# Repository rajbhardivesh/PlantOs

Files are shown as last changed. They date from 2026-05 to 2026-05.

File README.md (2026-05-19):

# 🌱 PlantOS – Smart IoT Plant Monitoring & Automation System






---

## 🚀 Overview

**PlantOS** is a complete **IoT-based plant monitoring and automation system** designed for real-world deployment.

It integrates:
- 📡 Embedded Firmware (ESP32)
- ⚡ Custom PCB Hardware
- 🌐 Web Dashboard
- ☁️ MQTT Cloud Communication

The system continuously monitors environmental conditions and automatically controls irrigation and lighting.

---

## 📸 Hardware Preview

Custom ESP32-based PCB for plant monitoring and automation.

---

## ✨ Key Features

### 🌡️ Multi-Sensor Monitoring
- DHT22 → Temperature & Humidity  
- DS18B20 → High-accuracy temperature  
- PT100 → Industrial temperature sensing  
- BH1750 → Light intensity (Lux)  
- MQ135 → Air quality monitoring  
- Soil Moisture Sensor  

---

### ⚡ Smart Automation
- 💧 Automatic irrigation based on soil moisture  
- 💡 Automatic lighting based on ambient lux  
- ⚙️ Relay-based control system  

---

### 🌐 IoT Connectivity
- WiFi provisioning via Serial interface  
- Secure MQTT communication (TLS supported)  
- Real-time JSON data streaming  

---

### 🧠 Intelligent Calibration System

Supports runtime calibration via commands:

```
cal dht_temp
cal soil
cal pt100
cal mq135
```

✔ Stored in non-volatile memory (NVS)  
✔ No need to reconfigure after reboot  

---

### 💡 LED Status Indicator

| State | Meaning |
|---|---|
| 🔴 Solid | No WiFi |
| 🔴 Blinking | WiFi connected, MQTT disconnected |
| 🔵 Blinking | Fully connected |

---

## 🧱 Hardware Specifications

### 🔌 Microcontroller
- ESP32

### 🔁 Outputs
| Device | GPIO |
|---|---|
| Pump Relay | GPIO21 |
| Light Relay | GPIO19 |

### 📥 Inputs
| Sensor | GPIO |
|---|---|
| DHT22 | GPIO4 |
| BH1750 | GPIO25, GPIO26 |
| MQ135 | GPIO14 |
| DS18B20 | GPIO32 |
| Soil Sensor | GPIO33 |
| PT100 | GPIO36 |

---

## 📡 MQTT Configuration

### Default Settings

```json
{
  "server": "f388acb36bf542b69c0c3cb96cb2cb16.s1.eu.hivemq.cloud",
  "port": 8883,
  "user": "plantos",
  "topic": "device/RDH001/data"
}
```

---

## 📊 Data Format (Published JSON)

```json
{
  "ssid": "YourWiFi",
  "dht_temp": 28.5,
  "dht_hum": 60.2,
  "soil_pct": 45.0,
  "lux": 320.5,
  "mq135": 210,
  "ds18b20": 27.1,
  "pt100": 26.9,
  "relay1": true,
  "relay2": false
}
```

---

## 🧩 Repository Structure

```
root/
│
├── index.html          # 🌐 Web Dashboard
├── web/src             # Frontend (JS, CSS)
├── pcb/source          # PCB Design Files
├── firmware            # ESP32 Firmware
```

---

## ⚙️ Setup Guide

### 1. Flash Firmware
- Open in Arduino IDE / PlatformIO  
- Select ESP32 board  
- Upload firmware  

### 2. Configure WiFi

Open Serial Monitor (115200 baud):

```
connect
```

### 3. Configure MQTT (Optional)

```
connect mqtt
```

### 4. Launch Dashboard

Open:
```
index.html
```

---

## 📟 Serial Commands

| Command | Description |
|---|---|
| connect | Scan WiFi |
| connect mqtt | Configure MQTT |
| status | System status |
| help | Show commands |
| cal <sensor> | Calibrate |

---

## 🔄 Automation Logic

### Pump
- ON → Soil < 25%
- OFF → Soil > 80%

### Light
- ON → Lux < 200
- OFF → Lux > 10000

---

## 🧠 Firmware Highlights

- Non-blocking state machine
- Auto reconnect WiFi
- MQTT keep-alive
- Persistent storage (NVS)
- JSON telemetry system

---

## 🌍 Use Cases

- Smart Agriculture
- Greenhouses
- Indoor Plants
- Research Labs
- Industrial IoT

---

## 📈 Future Roadmap

- Mobile App
- OTA Updates
- Cloud Dashboard
- LoRa Mode
- AI Automation

---

## Speacial  Thanks To 
PCB Design :  Rajbhar Divesh
Firmware & Web Dashboard: Varikar Manan 
 : 
## Author
** Varikar Manan **
## back-end Author 
** himanshu dave **

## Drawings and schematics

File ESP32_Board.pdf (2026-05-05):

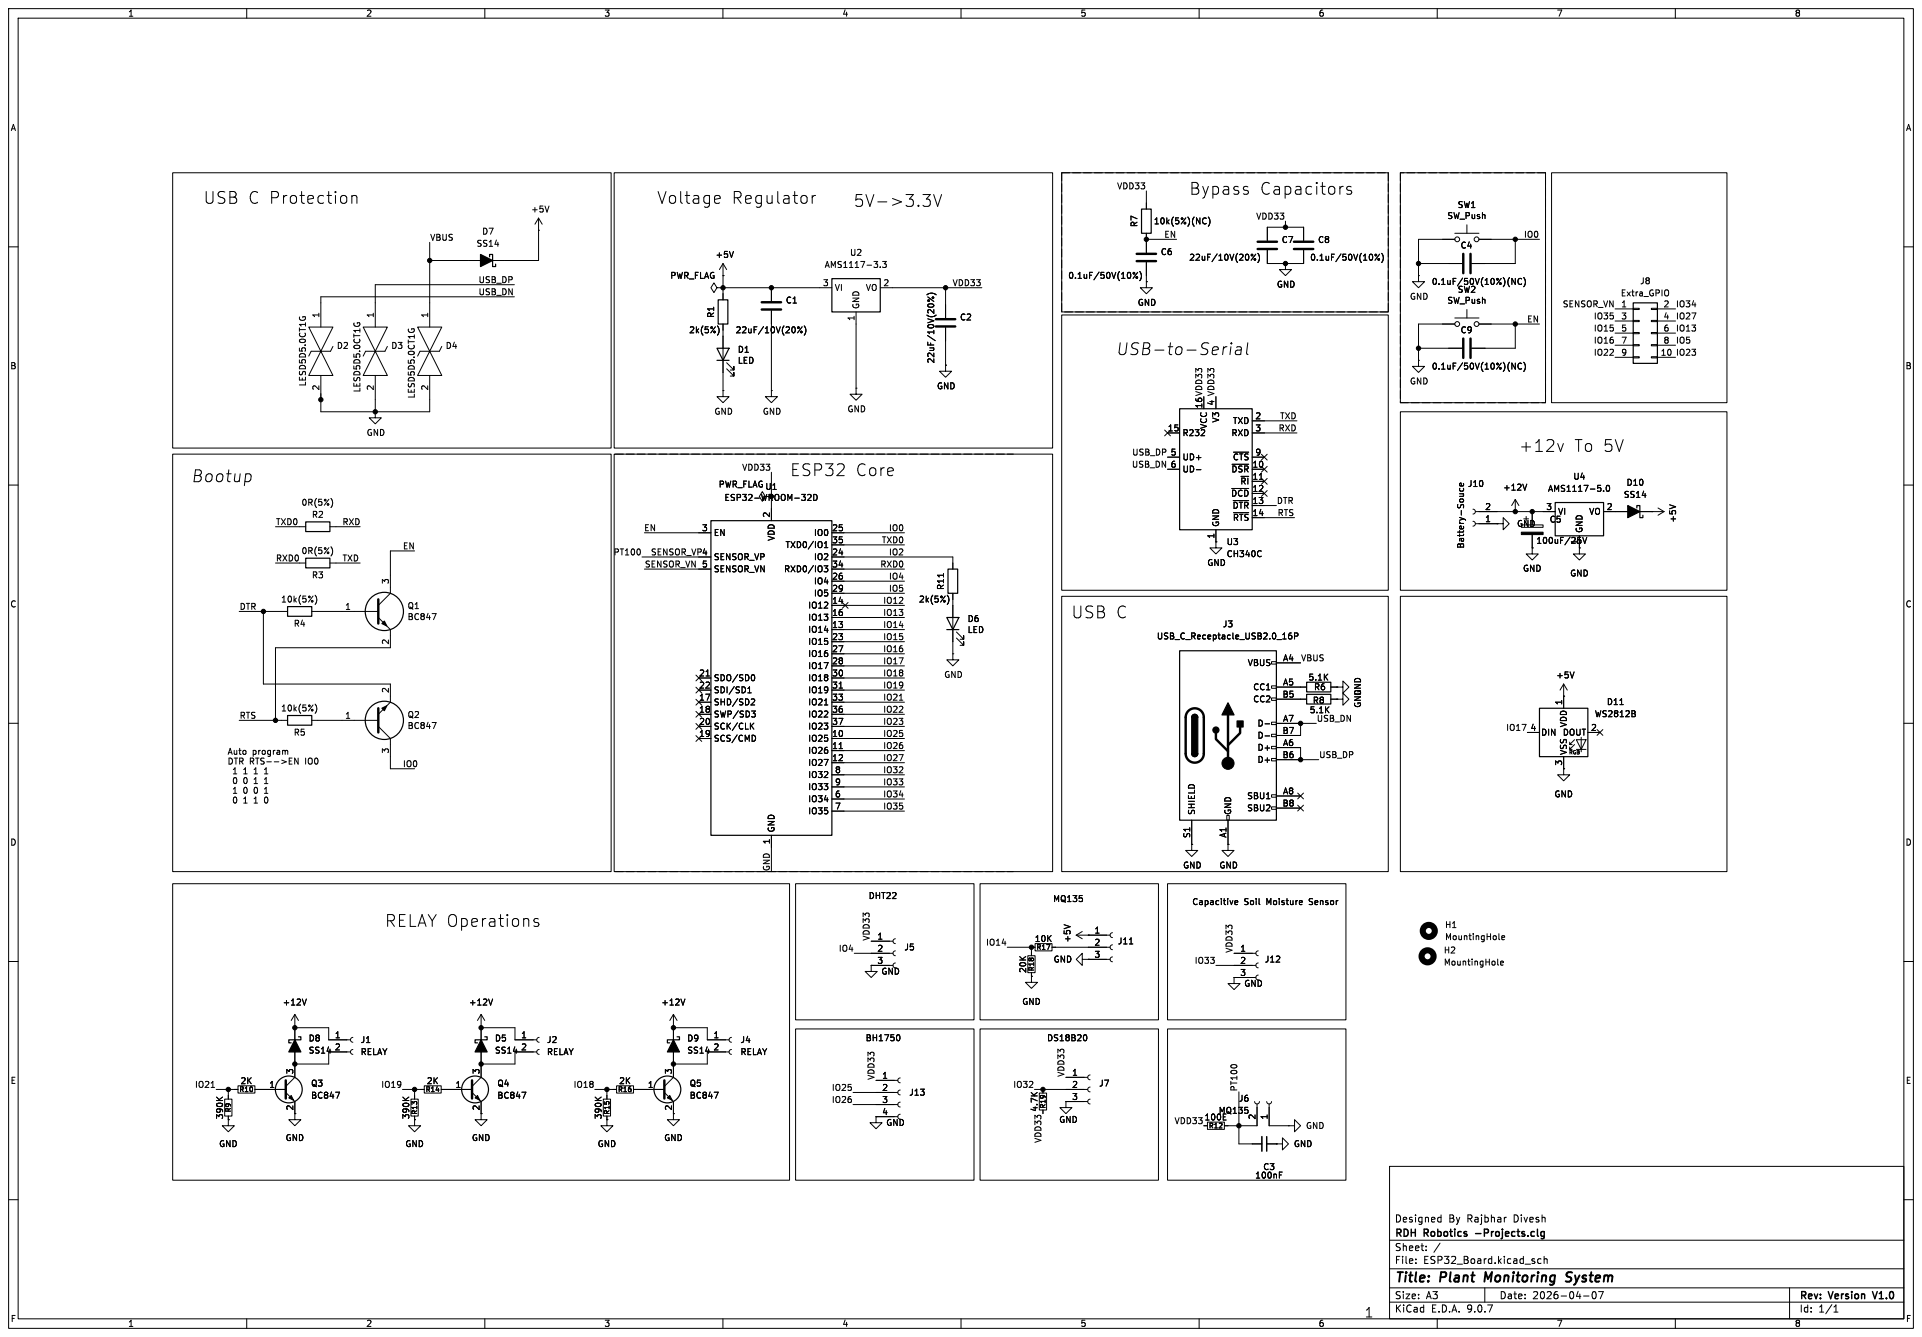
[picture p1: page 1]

1 TXD 2 RXD 3 ~{CTS}9 ~{DSR} 10 ~{RI} 11 ~{DCD} 12 ~{DTR} 13 ~{RTS} 14 U3 CH340C GND

1 TXD 2 RXD 3 ~{CTS}9 ~{DSR} 10 ~{RI} 11 ~{DCD} 12 ~{DTR} 13 ~{RTS} 14 GND

3 DOUT 2 D11 WS2812B SHIELD S1 GND A1 VBUS A4 CC1 A5 CC2 B5 D- A7 D- B7 D+ A6 D+ B6 SBU1 A8 SBU2 B8

Id: 1/1 Title: Plant Monitoring System

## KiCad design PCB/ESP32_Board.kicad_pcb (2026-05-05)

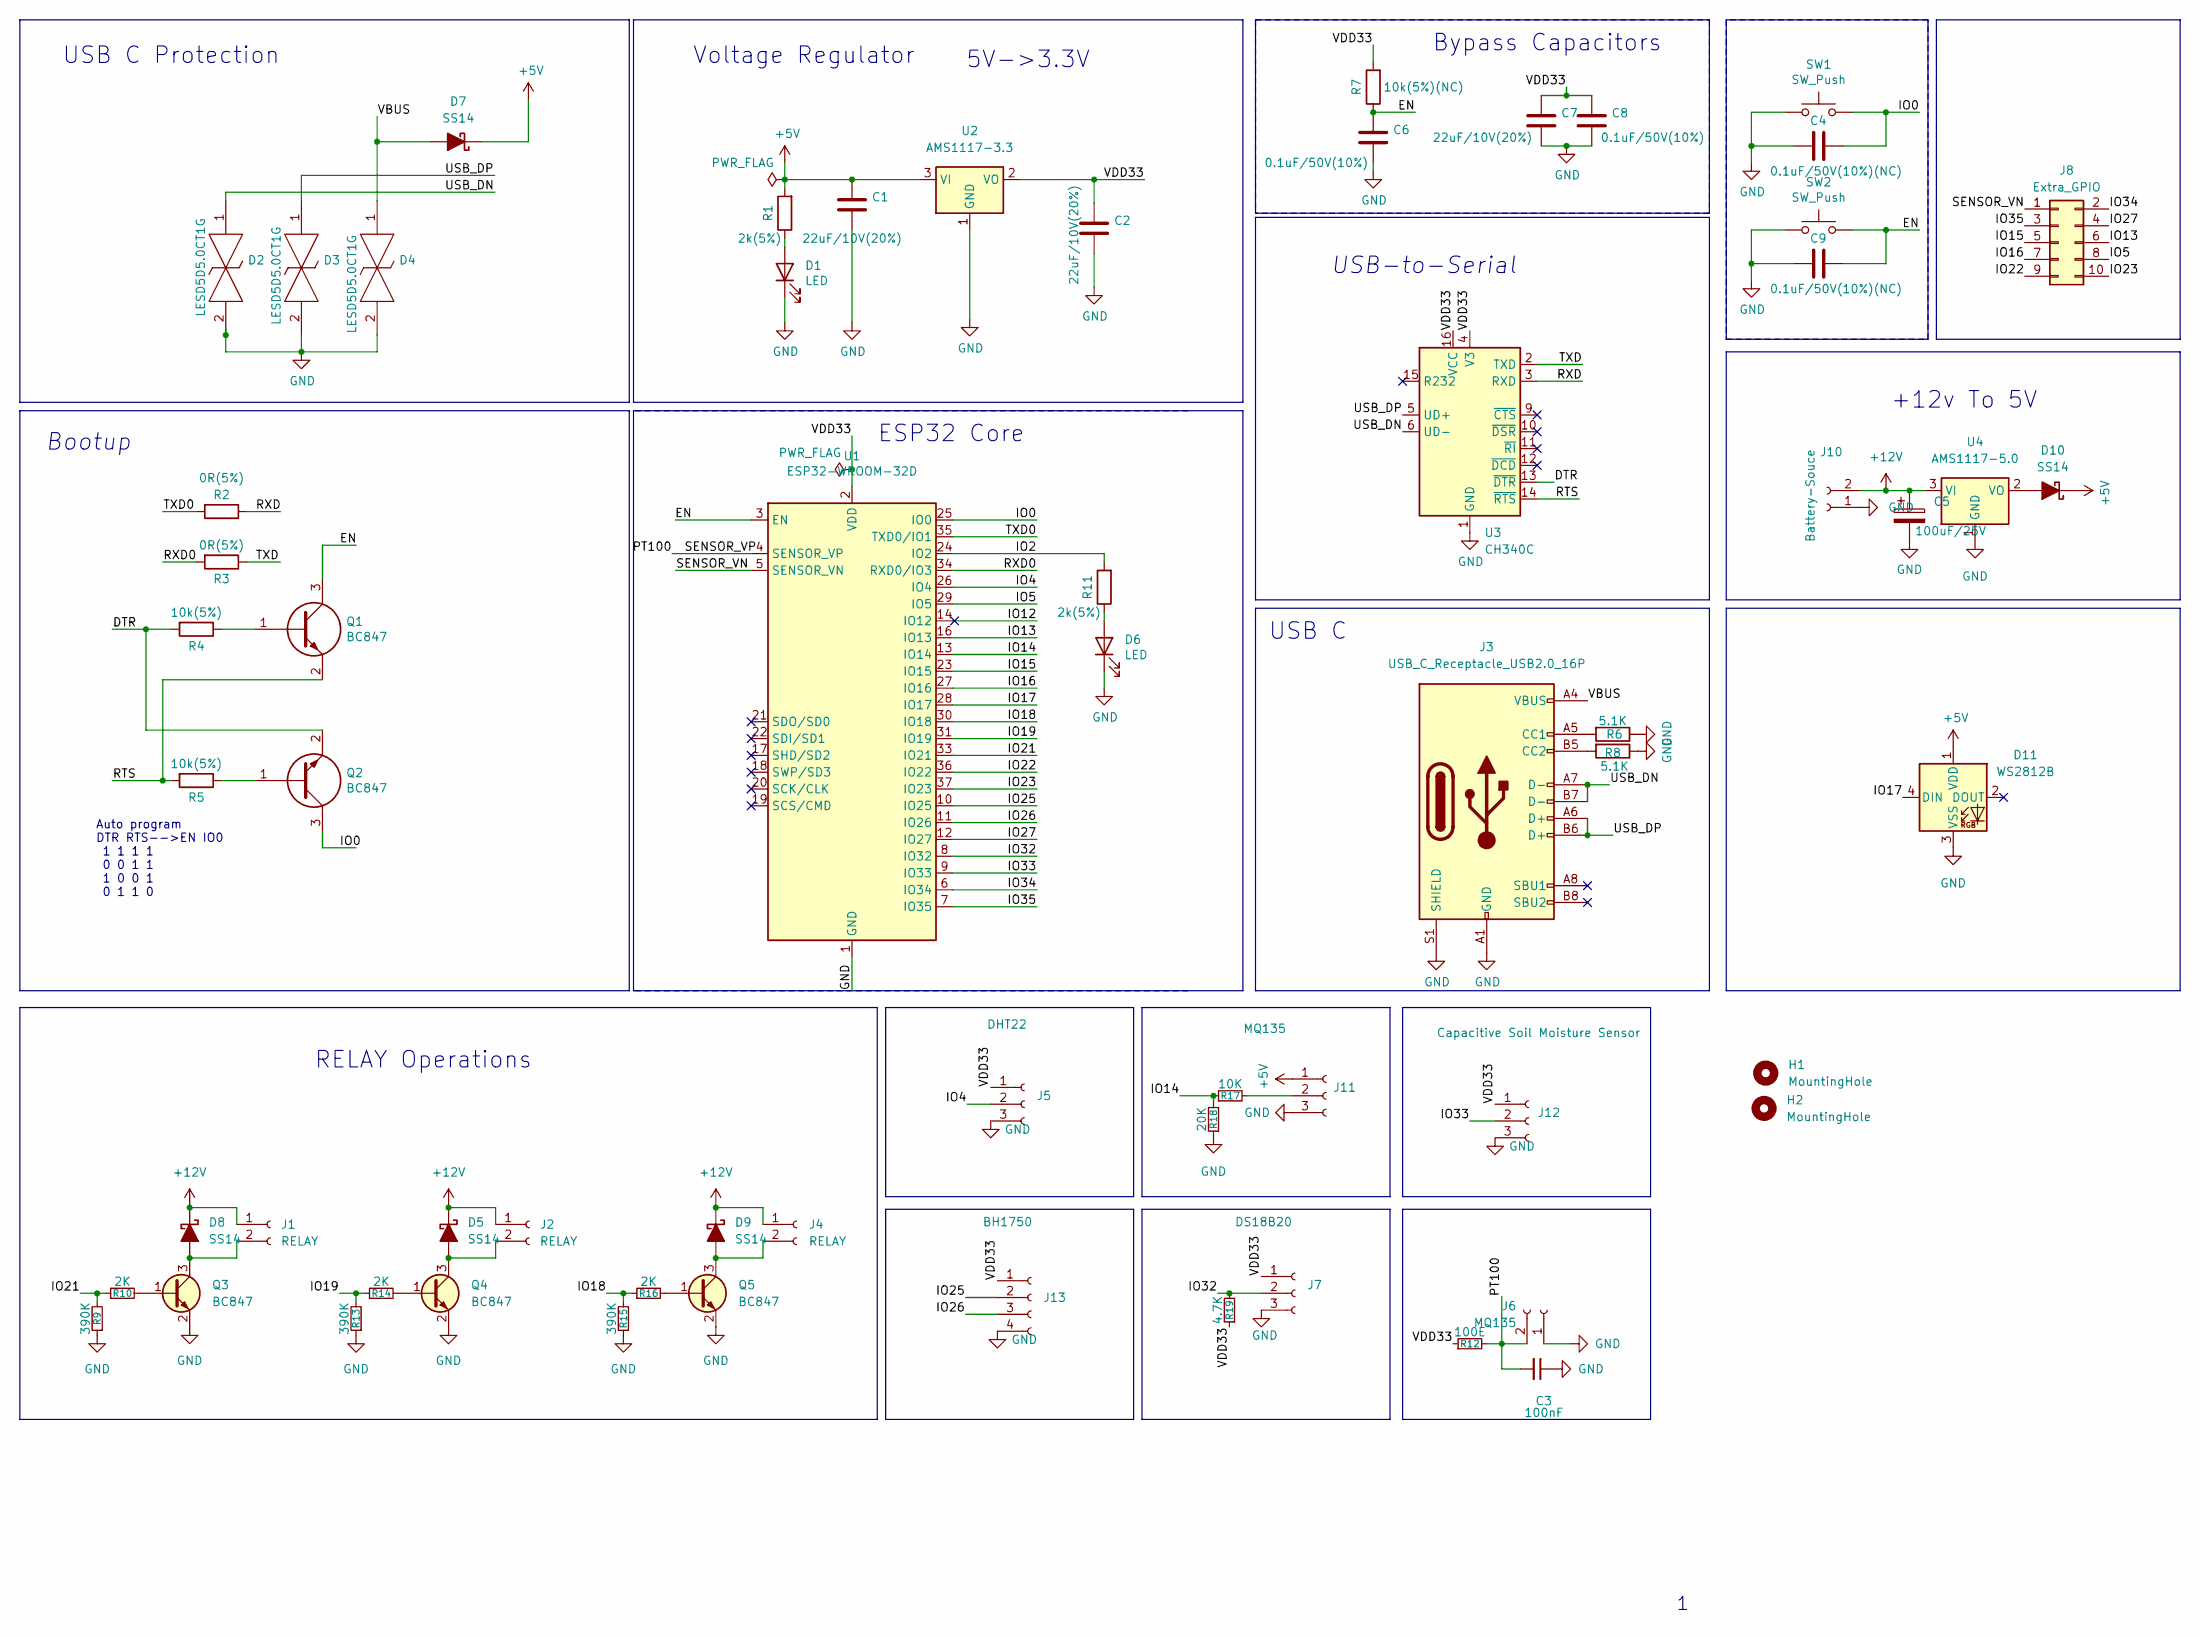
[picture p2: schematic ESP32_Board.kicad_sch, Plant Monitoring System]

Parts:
C1, C2, C7: 22uF/10V(20%); C_0805_2012Metric_Pad1.18x1.45mm_HandSolder
C3: 100nF; C_0805_2012Metric_Pad1.18x1.45mm_HandSolder
C4, C9: 0.1uF/50V(10%)(NC); C_0805_2012Metric_Pad1.18x1.45mm_HandSolder
C5: 100uF/25V; CP_Elec_6.3x7.7
C6, C8: 0.1uF/50V(10%); C_0805_2012Metric_Pad1.18x1.45mm_HandSolder
D1, D6: LED; LED_0805_2012Metric_Pad1.15x1.40mm_HandSolder
D2, D3, D4: LESD5D5.0CT1G; LESD5D50CT1G; Manufacturer_Part_Number LESD5D5.0CT1G
D5, D7, D8, D9, D10: SS14; D_SOD-123
D11: WS2812B; LED_WS2812B_PLCC4_5.0x5.0mm_P3.2mm
H1, H2: MountingHole; MountingHole_3.2mm_M3
J1, J2, J4: RELAY; JST_PH_B2B-PH-K_1x02_P2.00mm_Vertical
J3: USB_C_Receptacle_USB2.0_16P; USB_C_Receptacle_GCT_USB4105-xx-A_16P_TopMnt_Horizontal
J5: DHT22; JST_PH_B3B-PH-K_1x03_P2.00mm_Vertical
J6: MQ135; JST_PH_B2B-PH-K_1x02_P2.00mm_Vertical
J7: DS18B20; JST_PH_B3B-PH-K_1x03_P2.00mm_Vertical
J8: Extra_GPIO; PinHeader_2x05_P2.54mm_Vertical
J10: Battery-Souce; JST_PH_B2B-PH-K_1x02_P2.00mm_Vertical
J11: MQ135; JST_PH_B3B-PH-K_1x03_P2.00mm_Vertical
J12: Capacitive Soil Moisture Sensor; JST_PH_B3B-PH-K_1x03_P2.00mm_Vertical
J13: BH1750; JST_PH_B4B-PH-K_1x04_P2.00mm_Vertical
Q1, Q2: BC847; SOT-23; Manufacturer_Part_Number SS8050-G; Mouser Part Number 750-SS8050-G
Q3, Q4, Q5: BC847; SOT-23
R1, R11: 2k(5%); R_0805_2012Metric_Pad1.20x1.40mm_HandSolder
R2, R3: 0R(5%); R_0805_2012Metric_Pad1.20x1.40mm_HandSolder
R4, R5: 10k(5%); R_0805_2012Metric_Pad1.20x1.40mm_HandSolder
R6, R8: 5.1K; R_0805_2012Metric_Pad1.20x1.40mm_HandSolder
R7: 10k(5%)(NC); R_0805_2012Metric_Pad1.20x1.40mm_HandSolder
R9, R13, R15: 390K; R_0805_2012Metric_Pad1.20x1.40mm_HandSolder
R10, R14, R16: 2K; R_0805_2012Metric_Pad1.20x1.40mm_HandSolder
R12: 100E; R_0805_2012Metric_Pad1.20x1.40mm_HandSolder
R17: 10K; R_0805_2012Metric_Pad1.20x1.40mm_HandSolder
R18: 20K; R_0805_2012Metric_Pad1.20x1.40mm_HandSolder
R19: 4.7K; R_0805_2012Metric_Pad1.20x1.40mm_HandSolder
SW1, SW2: SW_Push; SW_SPST_TS-1088-xR020
U1: ESP32-WROOM-32D; ESP32-WROOM-32
U2: AMS1117-3.3; SOT-223-3_TabPin2
U3: CH340C; SOIC-16_3.9x9.9mm_P1.27mm
U4: AMS1117-5.0; SOT-223-3_TabPin2

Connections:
+5V: C1.1, D7.1 (K), D10.1 (K), D11.1 (VDD), J11.1, R1.2, U2.3 (VI)
+12V: C5.1, D5.1 (K), D8.1 (K), D9.1 (K), J1.1, J2.1, J4.1, J10.2, U4.3 (VI)
/DTR: Q2.2, R4.2, U3.13 (~DTR)
/EN: C6.1, C9.2, Q1.3, R7.1, SW2.2, U1.3 (EN)
/IO0: C4.2, Q2.3, SW1.2, U1.25 (IO0)
/IO2: R11.2, U1.24 (IO2)
/IO4: J5.2, U1.26 (IO4)
/IO5: J8.8, U1.29 (IO5)
/IO12: U1.14 (IO12)
/IO13: J8.6, U1.16 (IO13)
/IO14: R17.1, R18.2, U1.13 (IO14)
/IO15: J8.5, U1.23 (IO15)
/IO16: J8.7, U1.27 (IO16)
/IO17: D11.4 (DIN), U1.28 (IO17)
/IO18: R15.2, R16.1, U1.30 (IO18)
/IO19: R13.2, R14.1, U1.31 (IO19)
/IO21: R9.2, R10.1, U1.33 (IO21)
/IO22: J8.9, U1.36 (IO22)
/IO23: J8.10, U1.37 (IO23)
/IO25: J13.2, U1.10 (IO25)
/IO26: J13.3, U1.11 (IO26)
/IO27: J8.4, U1.12 (IO27)
/IO32: J7.2, R19.2, U1.8 (IO32)
/IO33: J12.2, U1.9 (IO33)
/IO34: J8.2, U1.6 (IO34)
/IO35: J8.3, U1.7 (IO35)
/PT100: C3.2, J6.2, R12.2, U1.4 (SENSOR_VP)
/RTS: Q1.2, R5.2, U3.14 (~RTS)
/RXD: R2.1, U3.3 (RXD)
/RXD0: R3.2, U1.34 (RXD0/IO3)
/SENSOR_VN: J8.1, U1.5 (SENSOR_VN)
/TXD: R3.1, U3.2 (TXD)
/TXD0: R2.2, U1.35 (TXD0/IO1)
/USB_DN: D2.1, J3.A7 (D-), J3.B7 (D-), U3.6 (UD-)
/USB_DP: D3.1, J3.A6 (D+), J3.B6 (D+), U3.5 (UD+)
/VBUS: D4.1, D7.2 (A), J3.A4 (VBUS), J3.A9 (VBUS), J3.B4 (VBUS), J3.B9 (VBUS)
/VDD33: C2.1, C7.1, C8.1, J5.1, J7.1, J12.1, J13.1, R7.2, R12.1, R19.1, U1.2 (VDD), U2.2 (VO), U3.4 (V3), U3.16 (VCC)
GND: C1.2, C2.2, C3.1, C4.1, C5.2, C6.2, C7.2, C8.2, C9.1, D1.1 (K), D2.2, D3.2, D4.2, D6.1 (K), D11.3 (VSS), J3.A1 (GND), J3.A12 (GND), J3.B1 (GND), J3.B12 (GND), J3.S1 (SHIELD), J5.3, J6.1, J7.3, J10.1, J11.3, J12.3, J13.4, Q3.2 (E), Q4.2 (E), Q5.2 (E), R6.1, R8.1, R9.1, R13.1, R15.1, R18.1, SW1.1, SW2.1, U1.1 (GND), U1.15 (GND), U1.38 (GND), U1.39 (GND), U2.1 (GND), U3.1 (GND), U4.1 (GND)
unnamed: D1.2 (A), R1.1
unnamed: D5.2 (A), J2.2, Q4.3 (C)
unnamed: D6.2 (A), R11.1
unnamed: D8.2 (A), J1.2, Q3.3 (C)
unnamed: D9.2 (A), J4.2, Q5.3 (C)
unnamed: D10.2 (A), U4.2 (VO)
unnamed: J3.A5 (CC1), R6.2
unnamed: J3.B5 (CC2), R8.2
unnamed: J11.2, R17.2
unnamed: Q1.1, R4.1
unnamed: Q2.1, R5.1
unnamed: Q3.1 (B), R10.2
unnamed: Q4.1 (B), R14.2
unnamed: Q5.1 (B), R16.2

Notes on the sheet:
Bypass Capacitors
+12v To 5V
USB C Protection
RELAY Operations
Auto program DTR RTS-->EN IO0 1 1 1 1 0 0 1 1 1 0 0 1 0 1 1 0
Bootup
USB-to-Serial
Voltage Regulator
ESP32 Core
5V->3.3V
USB C

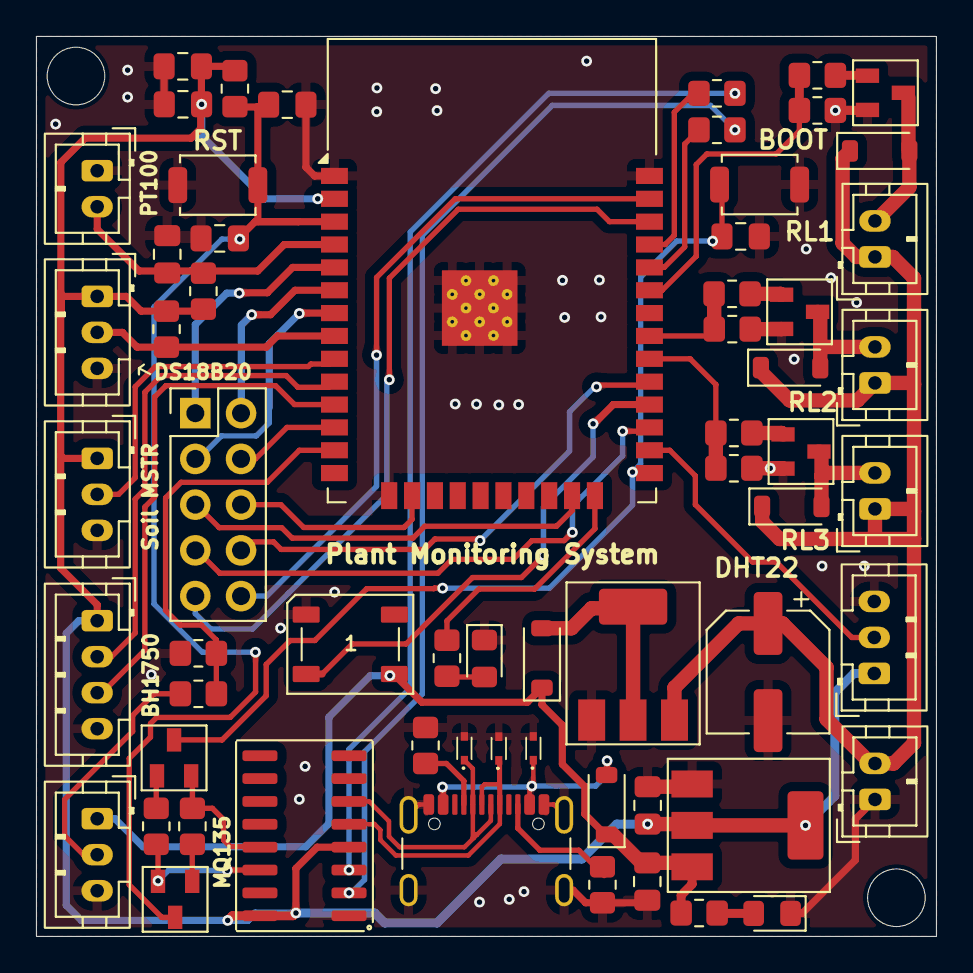
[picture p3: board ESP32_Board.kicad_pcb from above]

Board: 2 copper layers, 50.0 x 50.0 mm, 64 parts (0 on the bottom side), 51 nets.

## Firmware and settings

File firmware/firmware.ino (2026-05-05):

// ============================================================
//  PlantOS - Full Firmware
// ============================================================
#include <WiFi.h>
#include <WiFiClientSecure.h>
#include <PubSubClient.h>
#include <Adafruit_NeoPixel.h>
#include <DHT.h>
#include <Wire.h>
#include <BH1750.h>
#include <OneWire.h>
#include <DallasTemperature.h>
#include <Preferences.h>

// ============================================================
//  PIN DEFINITIONS
// ============================================================
#define LED_PIN         17
#define LED_COUNT       1
#define RELAY1_PIN      21   // PUMP
#define RELAY2_PIN      19   // LIGHT
#define DHT_PIN         4
#define BH1750_SDA      25
#define BH1750_SCL      26
#define MQ135_PIN       14   // ADC
#define DS18B20_PIN     32
#define SOIL_PIN        33   // ADC
#define PT100_PIN       36   // VP (ADC1_CH0)

// ============================================================
//  STORED CONFIG
// ============================================================
#define PREF_NS "plantos"

struct WiFiCreds {
  char ssid[64];
  char pass[64];
};

struct MQTTConfig {
  char server[128];
  int  port;
  char user[64];
  char pass[64];
  char topic[64];
};

WiFiCreds wifiCreds;
MQTTConfig mqttCfg;

// Default values
const char* DEFAULT_SERVER = "f388acb36bf542b69c0c3cb96cb2cb16.s1.eu.hivemq.cloud";
const int   DEFAULT_PORT   = 8883;
const char* DEFAULT_USER   = "plantos";
const char* DEFAULT_PASS   = "Plantos1";
const char* DEFAULT_TOPIC  = "device/RDH001/data";

// ============================================================
//  CALIBRATION OFFSETS (stored in NVS)
// ============================================================
struct CalData {
  float dht_temp_offset;
  float dht_hum_offset;
  float ds18b20_offset;
  float mq135_offset;
  int   soil_dry;
  int   soil_wet;
  float pt100_ref_ohm;
  float pt100_ref_temp;
};

CalData cal;

const CalData CAL_DEFAULTS = {
  .dht_temp_offset  = 0.0f,
  .dht_hum_offset   = 0.0f,
  .ds18b20_offset   = 0.0f,
  .mq135_offset     = 0.0f,
  .soil_dry         = 3500,
  .soil_wet         = 1500,
  .pt100_ref_ohm    = 100.0f,
  .pt100_ref_temp   = 0.0f
};

// ============================================================
//  RELAY THRESHOLDS
// ============================================================
#define SOIL_ON_THRESHOLD    25.0f
#define SOIL_OFF_THRESHOLD   80.0f
#define LUX_ON_THRESHOLD     200.0f
#define LUX_OFF_THRESHOLD    10000.0f

// ============================================================
//  GLOBAL OBJECTS
// ============================================================
WiFiClientSecure net;
PubSubClient     client(net);
Adafruit_NeoPixel led(LED_COUNT, LED_PIN, NEO_GRB + NEO_KHZ800);
DHT              dht(DHT_PIN, DHT22);
BH1750           lightMeter;
OneWire          oneWire(DS18B20_PIN);
DallasTemperature ds18b20(&oneWire);
Preferences      prefs;

// ============================================================
//  STATE
// ============================================================
bool wifiConnected  = false;
bool mqttConnected  = false;
bool bh1750Present  = false;
bool bh1750Checked  = false;
bool relay1State    = false;
bool relay2State    = false;

unsigned long lastMsg   = 0;
unsigned long lastBlink = 0;
bool          ledState  = false;

// ============================================================
//  CALIBRATION WAIT STATE
// ============================================================
enum CalStep { CAL_IDLE, CAL_WAIT_REF };
CalStep   calStep      = CAL_IDLE;
String    calSensor    = "";
float     calRawValue  = 0;

// ============================================================
//  SCAN RESULT STORAGE
// ============================================================
// Stores the last WiFi scan so the user can pick by number
// without re-scanning between the list display and password entry.
#define MAX_SCAN_RESULTS 20
String scannedSSIDs[MAX_SCAN_RESULTS];
int    scannedCount = 0;

// Interactive WiFi state machine
enum WiFiStep {
  WIFI_IDLE,
  WIFI_WAIT_CHOICE,
  WIFI_WAIT_PASSWORD
};
WiFiStep wifiStep     = WIFI_IDLE;
int      wifiChoice   = -1;  // 1-based index chosen by user

// ============================================================
//  NVS HELPERS
// ============================================================
void loadPreferences() {
  prefs.begin(PREF_NS, true);

  strncpy(wifiCreds.ssid, prefs.getString("w_ssid", "").c_str(), sizeof(wifiCreds.ssid));
  strncpy(wifiCreds.pass, prefs.getString("w_pass", "").c_str(), sizeof(wifiCreds.pass));

  strncpy(mqttCfg.server, prefs.getString("srv",   DEFAULT_SERVER).c_str(), sizeof(mqttCfg.server));
  mqttCfg.port = prefs.getInt("port", DEFAULT_PORT);
  strncpy(mqttCfg.user,  prefs.getString("user",   DEFAULT_USER).c_str(),   sizeof(mqttCfg.user));
  strncpy(mqttCfg.pass,  prefs.getString("pass",   DEFAULT_PASS).c_str(),   sizeof(mqttCfg.pass));
  strncpy(mqttCfg.topic, prefs.getString("topic",  DEFAULT_TOPIC).c_str(),  sizeof(mqttCfg.topic));

  cal.dht_temp_offset = prefs.getFloat("cal_dt", CAL_DEFAULTS.dht_temp_offset);
  cal.dht_hum_offset  = prefs.getFloat("cal_dh", CAL_DEFAULTS.dht_hum_offset);
  cal.ds18b20_offset  = prefs.getFloat("cal_ds", CAL_DEFAULTS.ds18b20_offset);
  cal.mq135_offset    = prefs.getFloat("cal_mq", CAL_DEFAULTS.mq135_offset);
  cal.soil_dry        = prefs.getInt("cal_sd",    CAL_DEFAULTS.soil_dry);
  cal.soil_wet        = prefs.getInt("cal_sw",    CAL_DEFAULTS.soil_wet);
  cal.pt100_ref_ohm   = prefs.getFloat("cal_pr", CAL_DEFAULTS.pt100_ref_ohm);
  cal.pt100_ref_temp  = prefs.getFloat("cal_pt", CAL_DEFAULTS.pt100_ref_temp);

  prefs.end();
}

void saveWiFiCreds() {
  prefs.begin(PREF_NS, false);
  prefs.putString("w_ssid", wifiCreds.ssid);
  prefs.putString("w_pass", wifiCreds.pass);
  prefs.end();
}

void saveCalibration() {
  prefs.begin(PREF_NS, false);
  prefs.putFloat("cal_dt", cal.dht_temp_offset);
  prefs.putFloat("cal_dh", cal.dht_hum_offset);
  prefs.putFloat("cal_ds", cal.ds18b20_offset);
  prefs.putFloat("cal_mq", cal.mq135_offset);
  prefs.putInt("cal_sd",   cal.soil_dry);
  prefs.putInt("cal_sw",   cal.soil_wet);
  prefs.putFloat("cal_pr", cal.pt100_ref_ohm);
  prefs.putFloat("cal_pt", cal.pt100_ref_temp);
  prefs.end();
}

void saveMQTTConfig() {
  prefs.begin(PREF_NS, false);
  prefs.putString("srv",   mqttCfg.server);
  prefs.putInt("port",     mqttCfg.port);
  prefs.putString("user",  mqttCfg.user);
  prefs.putString("pass",  mqttCfg.pass);
  prefs.putString("topic", mqttCfg.topic);
  prefs.end();
}

// ============================================================
//  LED
// ============================================================
void setLED(uint8_t r, uint8_t g, uint8_t b) {
  led.setPixelColor(0, led.Color(r, g, b));
  led.show();
}

void handleLED() {
  if (!wifiConnected) {
    setLED(255, 0, 0);
    return;
  }
  if (!mqttConnected) {
    if (millis() - lastBlink > 500) {
      lastBlink = millis();
      ledState = !ledState;
      ledState ? setLED(255, 0, 0) : setLED(0, 0, 0);
    }
    return;
  }
  if (millis() - lastBlink > 500) {
    lastBlink = millis();
    ledState = !ledState;
    ledState ? setLED(0, 0, 255) : setLED(0, 0, 0);
  }
}

// ============================================================
//  RELAY CONTROL
// ============================================================
void setRelay(int pin, bool &state, bool on) {
  state = on;
  digitalWrite(pin, on ? HIGH : LOW);
}

// ============================================================
//  SENSOR READING
// ============================================================
float readDHTTemp()     { return dht.readTemperature() + cal.dht_temp_offset; }
float readDHTHumidity() { return dht.readHumidity()    + cal.dht_hum_offset; }

float readSoilMoisture() {
  int raw = analogRead(SOIL_PIN);
  float pct = map(raw, cal.soil_dry, cal.soil_wet, 0, 100);
  return constrain(pct, 0.0f, 100.0f);
}

float readMQ135() {
  return analogRead(MQ135_PIN) + cal.mq135_offset;
}

float readDS18B20() {
  ds18b20.requestTemperatures();
  float t = ds18b20.getTempCByIndex(0);
  if (t == DEVICE_DISCONNECTED_C) return NAN;
  return t + cal.ds18b20_offset;
}

float readPT100() {
  int   raw     = analogRead(PT100_PIN);
  float voltage = raw * (3.3f / 4095.0f);
  float r_pt100 = (voltage * 100.0f) / (3.3f - voltage);
  float R0 = cal.pt100_ref_ohm / (1.0f + 3.9083e-3f * cal.pt100_ref_temp);
  float temp = (r_pt100 / R0 - 1.0f) / 3.9083e-3f;
  return temp;
}

float readLux() {
  if (!bh1750Present) return NAN;
  return lightMeter.readLightLevel();
}

// ============================================================
//  RELAY AUTOMATION
// ============================================================
void handleRelays(float moisture, float lux) {
  if (!isnan(moisture)) {
    if (!relay1State && moisture < SOIL_ON_THRESHOLD)
      setRelay(RELAY1_PIN, relay1State, true);
    else if (relay1State && moisture > SOIL_OFF_THRESHOLD)
      setRelay(RELAY1_PIN, relay1State, false);
  }
  if (!isnan(lux)) {
    if (!relay2State && lux < LUX_ON_THRESHOLD)
      setRelay(RELAY2_PIN, relay2State, true);
    else if (relay2State && lux > LUX_OFF_THRESHOLD)
      setRelay(RELAY2_PIN, relay2State, false);
  }
}

// ============================================================
//  BUILD + PUBLISH JSON
// ============================================================
void publishData() {
  if (millis() - lastMsg < 5000) return;
  lastMsg = millis();

  float moisture = readSoilMoisture();
  float lux      = readLux();
  float dhtTemp  = readDHTTemp();
  float dhtHum   = readDHTHumidity();
  float dsTemp   = readDS18B20();
  float mq135    = readMQ135();
  float pt100    = readPT100();

  handleRelays(moisture, lux);

  char payload[512];
  char luxBuf[16], dsTempBuf[16];

  if (isnan(lux))    snprintf(luxBuf,    sizeof(luxBuf),    "null");
  else               snprintf(luxBuf,    sizeof(luxBuf),    "%.2f", lux);

  if (isnan(dsTemp)) snprintf(dsTempBuf, sizeof(dsTempBuf), "null");
  else               snprintf(dsTempBuf, sizeof(dsTempBuf), "%.2f", dsTemp);

  snprintf(payload, sizeof(payload),
    "{"
      "\"ssid\":\"%s\","
      "\"dht_temp\":%.2f,"
      "\"dht_hum\":%.2f,"
      "\"soil_pct\":%.1f,"
      "\"lux\":%s,"
      "\"mq135\":%.0f,"
      "\"ds18b20\":%s,"
      "\"pt100\":%.2f,"
      "\"relay1\":%s,"
      "\"relay2\":%s"
    "}",
    WiFi.SSID().c_str(),
    dhtTemp, dhtHum,
    moisture,
    luxBuf,
    mq135,
    dsTempBuf,
    pt100,
    relay1State ? "true" : "false",
    relay2State ? "true" : "false"
  );

  client.publish(mqttCfg.topic, payload);
  Serial.println(payload);
}

// ============================================================
//  CALIBRATION LOGIC
// ============================================================
void startCalibration(String sensor) {
  sensor.toLowerCase();
  calSensor = sensor;

  if (sensor == "soil") {
    Serial.println("SOIL CAL: Place sensor in AIR (dry), then enter '0'");
    Serial.println("          Or place in WATER and enter '100'");
    Serial.println("Enter reference value (0 = dry / 100 = wet):");
    calRawValue = analogRead(SOIL_PIN);
  } else if (sensor == "dht_temp") {
    calRawValue = dht.readTemperature();
    Serial.printf("  Raw: %.2f C\n", calRawValue);
    Serial.println("Enter REFERENCE temperature (C):");
  } else if (sensor == "dht_hum") {
    calRawValue = dht.readHumidity();
    Serial.printf("  Raw: %.2f %%\n", calRawValue);
    Serial.println("Enter REFERENCE humidity (%%):");
  } else if (sensor == "ds18b20") {
    ds18b20.requestTemperatures();
    calRawValue = ds18b20.getTempCByIndex(0);
    Serial.printf("  Raw: %.2f C\n", calRawValue);
    Serial.println("Enter REFERENCE temperature (C):");
  } else if (sensor == "mq135") {
    calRawValue = analogRead(MQ135_PIN);
    Serial.printf("  Raw ADC: %.0f\n", calRawValue);
    Serial.println("Enter REFERENCE clean-air ADC value:");
  } else if (sensor == "pt100") {
    calRawValue = readPT100();
    Serial.printf("  Current reading: %.2f C\n", calRawValue);
    Serial.println("Enter REFERENCE temperature (C):");
  } else {
    Serial.println("Unknown sensor. Options: dht_temp, dht_hum, ds18b20, mq135, soil, pt100");
    calStep = CAL_IDLE;
    return;
  }
  calStep = CAL_WAIT_REF;
}

void applyCalibration(float refValue) {
  if (calSensor == "dht_temp") {
    cal.dht_temp_offset = refValue - calRawValue;
    Serial.printf("DHT Temp offset: %.2f\n", cal.dht_temp_offset);
  } else if (calSensor == "dht_hum") {
    cal.dht_hum_offset = refValue - calRawValue;
    Serial.printf("DHT Hum offset: %.2f\n", cal.dht_hum_offset);
  } else if (calSensor == "ds18b20") {
    cal.ds18b20_offset = refValue - calRawValue;
    Serial.printf("DS18B20 offset: %.2f\n", cal.ds18b20_offset);
  } else if (calSensor == "mq135") {
    cal.mq135_offset = refValue - calRawValue;
    Serial.printf("MQ135 offset: %.2f\n", cal.mq135_offset);
  } else if (calSensor == "soil") {
    int raw = analogRead(SOIL_PIN);
    if ((int)refValue == 0) {
      cal.soil_dry = raw;
      Serial.printf("Soil DRY point saved: %d\n", raw);
    } else {
      cal.soil_wet = raw;
      Serial.printf("Soil WET point saved: %d\n", raw);
    }
  } else if (calSensor == "pt100") {
    int   raw     = analogRead(PT100_PIN);
    float voltage = raw * (3.3f / 4095.0f);
    float r_pt100 = (voltage * 100.0f) / (3.3f - voltage);
    cal.pt100_ref_ohm  = r_pt100;
    cal.pt100_ref_temp = refValue;
    Serial.printf("PT100 ref: %.2f Ohm @ %.2f C\n", r_pt100, refValue);
  }

  saveCalibration();
  Serial.println("Calibration saved.");
  calStep   = CAL_IDLE;
  calSensor = "";
}

// ============================================================
//  WIFI AUTO-RECONNECT (uses saved credentials)
// ============================================================
bool autoConnectWiFi() {
  if (strlen(wifiCreds.ssid) == 0) return false;

  // Disconnect cleanly before reconnecting to a (possibly new) SSID
  WiFi.disconnect(true);
  delay(200);

  Serial.printf("Auto-connecting to: %s\n", wifiCreds.ssid);
  strlen(wifiCreds.pass) == 0
    ? WiFi.begin(wifiCreds.ssid)
    : WiFi.begin(wifiCreds.ssid, wifiCreds.pass);

  int retry = 0;
  while (WiFi.status() != WL_CONNECTED && retry < 20) {
    delay(500); Serial.print("."); retry++;
  }
  Serial.println();
  if (WiFi.status() == WL_CONNECTED) {
    Serial.printf("WiFi Connected! IP: %s\n", WiFi.localIP().toString().c_str());
    wifiConnected = true;
    return true;
  }
  Serial.println("Auto-connect failed.");
  wifiConnected = false;
  return false;
}

// ============================================================
//  WIFI CONNECT - NON-BLOCKING SCAN + STATE MACHINE
//
//  Calling connectWiFiScan() starts the process:
//    1. Performs a blocking WiFi scan (takes ~2-3 s).
//    2. Prints numbered list of found networks.
//    3. Sets wifiStep = WIFI_WAIT_CHOICE so the loop() knows
//       the next Serial input is a network number.
//
//  The loop() then feeds further input into
//  handleWiFiInput() which advances the state machine:
//    WIFI_WAIT_CHOICE  -> user types a number -> saved, prompts password
//    WIFI_WAIT_PASSWORD -> user types password -> connect, save, MQTT
// ============================================================
void connectWiFiScan() {
  Serial.println("\nScanning for nearby WiFi networks, please wait...");

  // Disconnect first so the scan works properly even if already connected
  WiFi.disconnect(true);
  delay(100);
  wifiConnected = false;
  mqttConnected = false;

  int n = WiFi.scanNetworks();  // blocking scan

  if (n <= 0) {
    Serial.println("No networks found. Type 'connect' to try again.");
    wifiStep = WIFI_IDLE;
    return;
  }

  scannedCount = (n > MAX_SCAN_RESULTS) ? MAX_SCAN_RESULTS : n;
  Serial.println("\n--- Available Networks ---");
  for (int i = 0; i < scannedCount; i++) {
    scannedSSIDs[i] = WiFi.SSID(i);
    Serial.printf("  %d. %-32s  RSSI: %d dBm  %s\n",
      i + 1,
      scannedSSIDs[i].c_str(),
      WiFi.RSSI(i),
      (WiFi.encryptionType(i) == WIFI_AUTH_OPEN) ? "[Open]" : "[Secured]"
    );
  }
  Serial.println("--------------------------");
  Serial.println("Enter network number to connect:");

  wifiStep   = WIFI_WAIT_CHOICE;
  wifiChoice = -1;
}

// Called from loop() whenever a serial line arrives and wifiStep != WIFI_IDLE
void handleWiFiInput(String input) {
  input.trim();

  if (wifiStep == WIFI_WAIT_CHOICE) {
    int choice = input.toInt();
    if (choice < 1 || choice > scannedCount) {
      Serial.printf("Invalid choice. Please enter a number between 1 and %d:\n", scannedCount);
      return;  // stay in WIFI_WAIT_CHOICE
    }
    wifiChoice = choice;

    // Check if the network is open
    bool isOpen = (WiFi.encryptionType(wifiChoice - 1) == WIFI_AUTH_OPEN);
    Serial.printf("Selected: %s\n", scannedSSIDs[wifiChoice - 1].c_str());
    if (isOpen) {
      Serial.println("Open network detected, connecting without password...");
      // Treat as empty password
      handleWiFiInput("");  // reuse password handler with blank
      return;
    }
    Serial.println("Enter WiFi password (press Enter for open/no password):");
    wifiStep = WIFI_WAIT_PASSWORD;
    return;
  }

  if (wifiStep == WIFI_WAIT_PASSWORD) {
    String ssid = scannedSSIDs[wifiChoice - 1];
    String pass = input;  // already trimmed above

    // Disconnect cleanly before attempting new connection
    WiFi.disconnect(true);
    delay(200);

    Serial.printf("Connecting to: %s ...\n", ssid.c_str());
    if (pass.length() == 0) {
      WiFi.begin(ssid.c_str());
    } else {
      WiFi.begin(ssid.c_str(), pass.c_str());
    }

    int retry = 0;
    while (WiFi.status() != WL_CONNECTED && retry < 20) {
      delay(500); Serial.print("."); retry++;
    }
    Serial.println();

    if (WiFi.status() == WL_CONNECTED) {
      Serial.printf("WiFi Connected! IP: %s\n", WiFi.localIP().toString().c_str());
      wifiConnected = true;

      // Persist new credentials for future auto-reconnect
      strncpy(wifiCreds.ssid, ssid.c_str(), sizeof(wifiCreds.ssid));
      strncpy(wifiCreds.pass, pass.c_str(), sizeof(wifiCreds.pass));
      saveWiFiCreds();
      Serial.println("WiFi credentials saved.");

      // Reconnect MQTT on the new network
      connectMQTT();
    } else {
      Serial.println("WiFi connection failed. Type 'connect' to try again.");
      wifiConnected = false;
    }

    wifiStep   = WIFI_IDLE;
    wifiChoice = -1;
    return;
  }
}

// ============================================================
//  MQTT CONFIG EDITOR
// ============================================================

// Non-blocking MQTT config editor state machine
enum MQTTStep {
  MQTT_IDLE,
  MQTT_WAIT_SERVER,
  MQTT_WAIT_PORT,
  MQTT_WAIT_USER,
  MQTT_WAIT_PASS,
  MQTT_WAIT_TOPIC
};
MQTTStep mqttStep = MQTT_IDLE;

void startMQTTConfig() {
  Serial.println("\n--- MQTT Configuration ---");
  Serial.println("Press Enter to keep the current value shown in [ ].\n");
  Serial.printf("Server [%s]: ", mqttCfg.server);
  mqttStep = MQTT_WAIT_SERVER;
}

void handleMQTTInput(String input) {
  input.trim();

  switch (mqttStep) {
    case MQTT_WAIT_SERVER:
      if (input.length()) strncpy(mqttCfg.server, input.c_str(), sizeof(mqttCfg.server));
      Serial.printf("Port [%d]: ", mqttCfg.port);
      mqttStep = MQTT_WAIT_PORT;
      break;

    case MQTT_WAIT_PORT:
      if (input.length()) mqttCfg.port = input.toInt();
      Serial.printf("User [%s]: ", mqttCfg.user);
      mqttStep = MQTT_WAIT_USER;
      break;

    case MQTT_WAIT_USER:
      if (input.length()) strncpy(mqttCfg.user, input.c_str(), sizeof(mqttCfg.user));
      Serial.print("Pass (hidden): ");
      mqttStep = MQTT_WAIT_PASS;
      break;

    case MQTT_WAIT_PASS:
      if (input.length()) strncpy(mqttCfg.pass, input.c_str(), sizeof(mqttCfg.pass));
      Serial.printf("Topic [%s]: ", mqttCfg.topic);
      mqttStep = MQTT_WAIT_TOPIC;
      break;

    case MQTT_WAIT_TOPIC:
      if (input.length()) strncpy(mqttCfg.topic, input.c_str(), sizeof(mqttCfg.topic));
      saveMQTTConfig();
      Serial.println("MQTT config saved. Reconnecting...");
      client.disconnect();
      mqttConnected = false;
      if (wifiConnected) connectMQTT();
      mqttStep = MQTT_IDLE;
      break;

    default:
      mqttStep = MQTT_IDLE;
      break;
  }
}
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
void loop() {
  // Serial command input - read one full line when available
  if (Serial.available()) {
    String input = Serial.readStringUntil('\n');
    input.trim();

    // Priority order: calibration > MQTT config > WiFi scan > normal command
    if (calStep == CAL_WAIT_REF) {
      float ref = input.toFloat();
      applyCalibration(ref);

    } else if (mqttStep != MQTT_IDLE) {
      handleMQTTInput(input);

    } else if (wifiStep != WIFI_IDLE) {
      handleWiFiInput(input);

    } else {
      handleCommand(input);
    }
  }

  // WiFi watchdog - only reconnect if not in the middle of interactive setup
  if (wifiStep == WIFI_IDLE && wifiConnected && WiFi.status() != WL_CONNECTED) {
    Serial.println("[WARN] WiFi dropped. Attempting auto-reconnect...");
    wifiConnected = false;
    mqttConnected = false;
    autoConnectWiFi();
  }

  // If WiFi came back but was never connected (first boot, no saved creds), skip watchdog noise
  if (wifiStep == WIFI_IDLE && !wifiConnected && WiFi.status() != WL_CONNECTED
      && strlen(wifiCreds.ssid) > 0) {
    // Only retry auto-connect if we have saved creds and are not in interactive mode
    static unsigned long lastRetry = 0;
    if (millis() - lastRetry > 30000) {  // retry every 30 s
      lastRetry = millis();
      autoConnectWiFi();
    }
  }

  // MQTT keep-alive
  if (wifiConnected && !client.connected()) {
    mqttConnected = false;
    connectMQTT();
  }
  if (client.connected()) {
    mqttConnected = true;
    client.loop();
    publishData();
  }

  handleLED();
}

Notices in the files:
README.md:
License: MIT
